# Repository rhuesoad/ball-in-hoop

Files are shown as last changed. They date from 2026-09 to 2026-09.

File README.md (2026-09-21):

# Ball in a Double Hoop

Code, CAD and documents of the master's thesis *Flying Ball in a Hoop — Design
of New Didactic Devices for Teaching of Control Engineering* (Rafaël Hueso
Adelantado), electromechanical engineering (mechatronics), ULB, 2025–2026.

Supervisors: Prof. Michel Kinnaert and Laurent Catoire.

A ball rolls inside two concentric hoops, turned by a single motor. The inner
hoop has a 90° gap. Four control tasks of increasing difficulty are posed on it:

| Task | Goal | Simulation | Bench |
|---|---|---|---|
| T1 | Bring the ball back to the bottom and hold it there | works | works, both hoops |
| T2 | Tracking | works | works, both hoops |
| T3 | Loop the loop | works | the ball leaves the track near the top (95–104°) |
| T4 | Throw the ball through the gap and catch it inside | works | not ported yet |

The thesis (`docs/thesis.pdf`) gives the model, the controllers and the results.

## Layout

The project works with a simulation, made on **Matlab**, and real hardware built with 
3D printing, and controlled with a Raspberry Pi controller and **Python**. 

| Folder | Content |
|---|---|
| `matlab/` | Model, controllers, trajectory planning, scenarios, and one example run per scenario |
| `python/` | Code that runs on the Raspberry Pi and drives the bench |
| `cad/` | OpenSCAD source of every printed part, one file per part |
| `analysis/` | Notebook that produces the report figures from the bench captures |
| `docs/` | Thesis and defence |

Each folder has its own README.

## Hardware

ODrive S1 driver, D5065 motor, AMT102-V encoder, Raspberry Pi with a Pi Camera,
and the printed parts in `cad/`.

## Where to pick it up

- **T4 on the bench.** The simulation works because the hoop is steered during
  the flight so that the gap faces the ball when it crosses the inner hoop
  (`matlab/scenarios/closed_loop/T4/T4_flying_ball.m`). The bench code in
  `python/tasks/t4_*.py` predates this and still loads the old plan.
- **T3 on the bench.** The two kept trials show where the ball leaves the track.
- **The model tests the ball centre only** when deciding whether it passes the
  gap, not the whole ball, so a clean mode sequence in simulation does not
  guarantee the ball clears the edge.
- **Hardware **: There is a play on the connection piece. Try to start from there
   to try to get better results on the looping itself.
- **More generally**, starting by the conclusion of the defence could help knowing 
  where to start to make things better in this project.

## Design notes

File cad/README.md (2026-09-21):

# CAD — printed parts

OpenSCAD source of every printed part (tested on OpenSCAD 2021.01). Open a part
file, render (F6), export to STL.

| File | Part |
|---|---|
| `outer_hoop_down.scad`, `outer_hoop_up.scad` | Outer hoop, two halves |
| `inner_hoop_down.scad`, `inner_hoop_up.scad` | Inner hoop, two halves |
| `motor_support.scad` | Motor support with its floor brackets |
| `motor_link.scad` | Link between the motor shaft and the hoops |
| `odrive_plate.scad` | Plate holding the ODrive S1 |
| `camera_rail.scad` | Camera rail, bolted to the M6 grid |
| `camera_carriage.scad` | Camera carriage, slides on the rail |
| `camera_clearance_test.scad` | Coupons to tune the rail clearance to a printer |
| `assembly.scad` | Whole bench, exploded view and 2D drawings (not a print file) |

The part files only select what to render. The geometry lives in `bench.scad`
(hoops and motor mount) and `camera_mount.scad` (camera rail).

`lib/nutsnbolts.scad` is "Norm Nuts and Bolts" by Johannes Kneer, under GPLv3.

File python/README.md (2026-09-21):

# Python — bench

Runs on the Raspberry Pi connected to the ODrive and the camera.

## Requirements

Python 3 with `numpy`, `scipy`, `opencv-python`, `odrive`, and `picamera2`
(Raspberry Pi only).

## Layout

| Folder | Content |
|---|---|
| `common/` | Ball detection, control loop and logging, estimators, hoop geometry |
| `experiments/` | Identification experiments E1 to E4 |
| `tasks/` | Control tasks T1 to T4: one config and one runner each, and the plans exported from MATLAB |
| `tools/` | Camera calibration and capture, ODrive calibration and tuning, one-off bench checks |

| Experiment | Measures |
|---|---|
| E1 | Motor and hoop inertia and friction |
| E2 | Ball friction, from free oscillations |
| E3 | The whole acquisition chain, from a hoop step |
| E4 | Static friction between ball and track |

## Running

From this folder, as modules:

```bash
python3 -m tasks.t1_run --psi-init 45
T1_HOOP=inner python3 -m tasks.t1_run --psi-init 45
python3 -m experiments.e2_run
python3 -m tools.odrive_calibration
```

Each run writes a `.npz` capture.

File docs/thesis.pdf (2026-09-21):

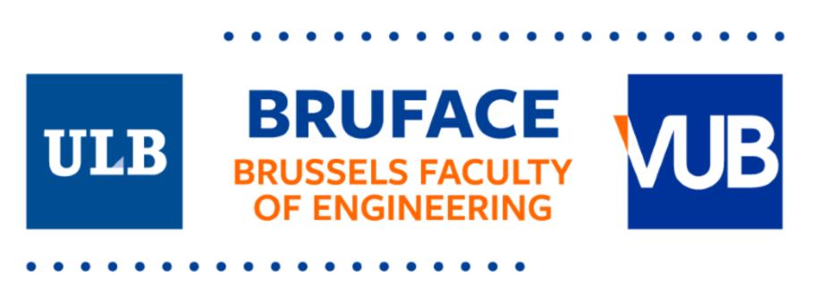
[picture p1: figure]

## [Date]

# Design of new didactic devices for teaching of control engineering

# Rafaël Hueso Adelantado

### Master thesis submitted under the supervision of

## Prof. Michel Kinnaert

### The co-supervision of

## Laurent Catoire

### In order to be awarded the Master’s Degree in

## Electromechanical Engineering – Robotics and Mechanical construction

### Academic year

2025-2026

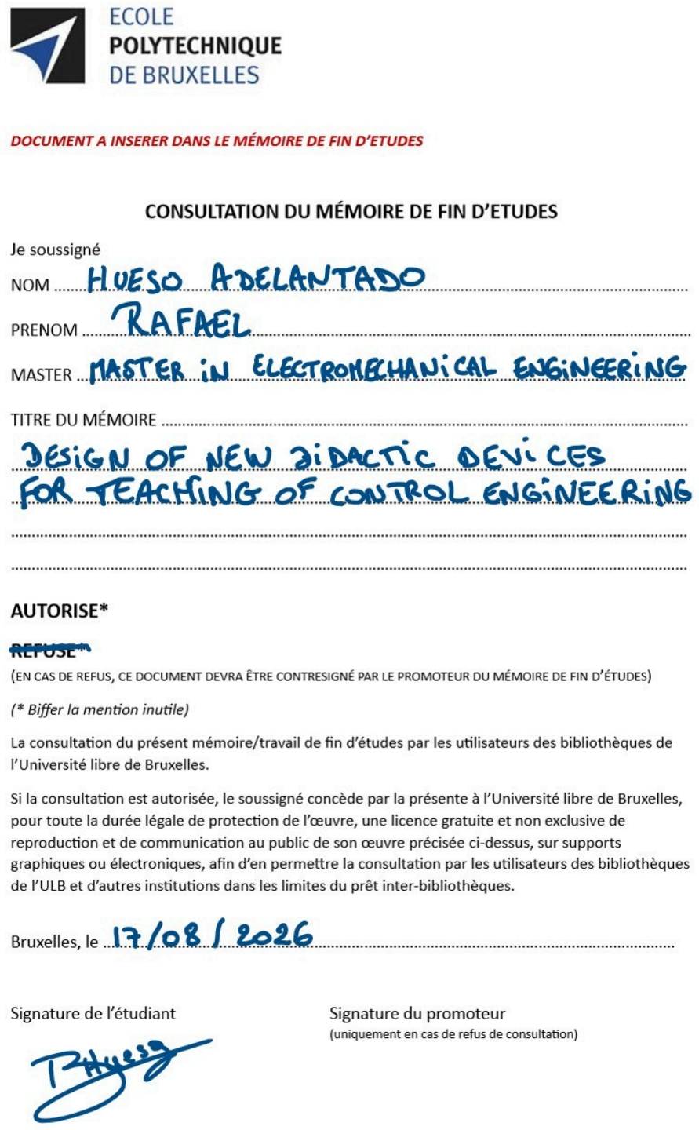
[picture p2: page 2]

Rafaël Hueso Adelantado
Master in Electromechanical Engineering - Robotics and Mechanical Construction Academic year 2025–2026
Design of new didactic devices for teaching of control engineering

Abstract

This thesis addresses the design, modelling, identification and control of a ball-and-hoop apparatus in double configuration, intended for the teaching of control engineering. The apparatus extends the single-hoop system introduced by Wellstead and takes as its starting point the double-hoop project of Gurtner and Zemánek, in which the ball may leave a rolling surface, travel through the air and land on another.
A hybrid model of the system is derived. It gives the ball access to four modes, three rolling modes and a free-flight mode, obtained from the Euler-Lagrange formalism, together with the guards and reset maps connecting them. The fourth mode follows from the opening cut in the inner hoop, which the published model does not cover. The resulting hybrid automaton is implemented and verified on a set of open-loop scenarios.
A prototype is then designed, built and characterised. Three experiments are performed on it to determine its parameters. The agreement between the model and the measured trajectories gives a mean root mean square error of 2.47° on the ball position.
Four control tasks of increasing difficulty are then formalised in a common optimal control framework. Stabilisation and reference tracking are achieved on the bench with a linear quadratic regulator, and the latency of the vision chain is shown to determine the loop rate below which the closed loop diverges, independently of the choice of gains. The looping manoeuvre is planned by direct collocation and stabilised by a time-varying regulator. It succeeds in simulation but fails systematically on the prototype, and the cause is traced to the reduced-order model, in which the no-slip constraint makes a violation of the law of Coulomb invisible to the optimiser. The flying ball task is consequently studied in simulation only.
The apparatus is functional as a teaching platform, and the modelling assumptions that limit its use for the harder tasks are identified explicitly.

Number of Words: 310
Keywords: ball-and-hoop, hybrid dynamical systems, optimal control, direct collocation, system identification, control engineering education.

i

## Acknowledgments

I would first like to express my gratitude to Professor Michel Kinnaert for his guidance throughout this thesis. His feedback and his expertise in the subject were crucial to this work. I also want to thank him for the freedom he left me in the direction it took.

I would also like to thank Laurent Catoire sincerely. His support was invaluable in the development of the prototype. I am grateful for the time he took to help me understand several technical aspects of the project, and for his patience whenever something had to be explained. His enthusiasm about the construction of the prototype made a real difference at a stage I was not confident about. I am also grateful to Fabio for making sure I had the widest possible access to the SAAS and to the printers that carried much of this work.

A special thanks goes to my music band. Without the PNTM, and now Sour, I would never have got through this year with the same determination.

Finally, I thank my family and friends for their support over the course of this year. Even when times were hard, I could always count on them. Special thanks to my mother, who convinced me never to give up, and to Paulina, Baptiste, Marion, Chloé, Anastasia, Gabor and all my friends and family, for making me feel supported and for giving me enormous confidence in my ability to finish this work.

ii

## Contents

Abstract | i
List of Figures | iv
List of Tables | vi
List of Abbreviations | vi
1 Introduction | 1
2 State Of The Art | 2
3 Mathematical Modelling | 10
4 System Design | 24
5 Parameter Identification | 32
6 Control Design | 43
7 Conclusion | 60

iii

Declaration of Generative AI and AI-assisted Technologies in the Writing Process | 61
Bibliography | 64
Appendices | 65
A Complete friction model for the ball | 65
B Field-Oriented Control | 67
C Inner Control Loop | 69
D Camera model and Image Acquisition | 71

## List of Figures

1.1 The prototype built in this work | | 1
2.1 First ball-and-hoop apparatus, motivated by the analogy with liquid sloshing | | 2
2.2 Flying Ball in Hoop prototype developed by the AA4CC group [2] | | 3
2.3 Common underactuated benchmarks. Each system has two degrees of freedom for a
single input. The actuated coordinate is shown in green, the free one in blue | | 3
2.4 Single-hoop configuration and its coordinates | | 5
2.5 Modes of the hybrid description of the ball-and-hoop system and the transitions between
them, following [2] | | 7
3.1 Diagram of the double-hoop system configuration | | 10
3.2 Hybrid automaton of the ball-in-double-hoop system. Each arrow is triggered when the corresponding guard vanishes. Losses of contact are governed by γ1, γ2 and γ3, impacts
by γ4, γ5 and γ6, and the passage over the opening of the inner hoop by γhole | 20
3.3 Open-loop trajectories of the six scenarios, released with τ = 0. The blue dot marks the initial position of the ball and the blue line its trajectory. Red dots mark the positions
at which a transition is triggered. The hoops are drawn at their starting orientation. . 22 4.1 Block diagram of the apparatus, showing the four subsystems and the signals exchanged
between them | | 25
4.2 CAD model of the two hoops, showing the tracks and the opening of the inner hoop. . | 27
4.3 Printed parts holding the apparatus | | 30
4.4 Electrical architecture of the prototype | | 31
5.1 Contact geometry of the idealised model and of the real prototype | | 32
5.2 Single frame from the vision chain, with the raw image, the separation through the
threshold and the detected ball centroid | | 33
5.3 Circles returned by the Hough transform on the same view | | 34
5.4 Steady-state torque against steady-state angular velocity, in both directions of rotation,
with the regression of each branch | 36
5.5 Free deceleration of the rotating assembly, with the regressions performed over the valid
portion of each run | 37
5.6 Free response of the ball released from several starting angles on the outer hoop, super-
posed over the trials | 38

iv

5.7 Extrema of a single trial and the two candidate envelopes fitted to them. The left panels
are in linear scale, the right ones in logarithmic scale, where a viscous decay appear as
a straight line | | 39
5.8 Measured hoop position over the trials of the campaign | | 40
5.9 Measured ball position over the trials, with the mean trajectory and the simulated one
superposed | 41
6.1 Measured ball position at two loop frequencies, with identical gains and from compa-
rable initial excursions | 48
6.2 Comparison between experimental LQR recovery trajectories and aligned simulations
from the same initial conditions | 49
6.3 Comparison between the tracking performance with the factory gains of the inner loop
(red) and the tuned gain (blue) values | 51
6.4 Measured ball position against its reference, with the hoop angle commanded by the
regulator shown on the right axis | | 51
6.5 Nominal trajectory of the looping manoeuvre | | 54
6.6 Simulation of the looping manoeuvre | | 55
6.7 Results of the looping manoeuvre on the bench, compared to the simulation results.
The simulation does the loop, while the bench fails | 56
6.8 Multi-phase trajectory of the flying ball manoeuvre, with the transitions marked in red. 59 B.1 Field-oriented current control loop as implemented on the ODrive S1. The outer loop control laws enter at the left of this loop, as a torque request converted to i

ref
q

through
the constant Kt
| 68
C.1 Step response of the inner velocity loop, with the factory gains, with the first-order response targeted by the design, and with the computed gains applied to the bench. . 70

v

## List of Tables

3.1 Physical parameters of the ball-and-hoop system | | 11
3.2 Parameters of the three rolling surfaces | | 13
4.1 Comparison of the ball candidates | | 25
5.1 Parameters identified in E1, averaged over the two directions of rotation | | 37
5.2 Physical parameters of the ball-and-hoop system | | 42
5.3 Physical parameters of the ball-and-hoop system, additions after component selection
and assembly | | 42
6.1 Equilibria of the ball-hoop system in each rolling mode | | 45
6.2 Retained weights for task T1 | | 47
6.3 Performance of the regulator against the specifications of task T1, for the outer hoop. | 49
A.1 Static friction coefficient required to maintain rolling contact, from (A.4) | | 65
C.1 Rise time, settling time and overshoot of the three step responses of Figure C.1 | | 70

## List of Abbreviations

BLDC | Brushless Direct Current
CPR | Counts Per Revolution
FOC | Field-Oriented Control
FOV | Field Of View
LQG | Linear Quadratic Gaussian
LQR | Linear Quadratic Regulator
NBR | Acrylonitrile Butadiene Rubber
OCP | Optimal Control Problem
PID | Proportional-Integral-Derivative
PLA | Polylactic Acid
PMSM | Permanent Magnet Synchronous Machine
PPR | Pulses Per Revolution
RMSE | Root Mean Square Error
TVLQR | Time-Varying Linear Quadratic Regulator

vi

## 1 Introduction

The objective of this master thesis is to design, control and implement a didactic device for the teaching of control engineering. The device selected in this document is a flying ball in a hoop. Students discover the dynamics of the system through lab sessions and learn to implement a control strategy bringing the ball onto the inner hoop of the prototype.

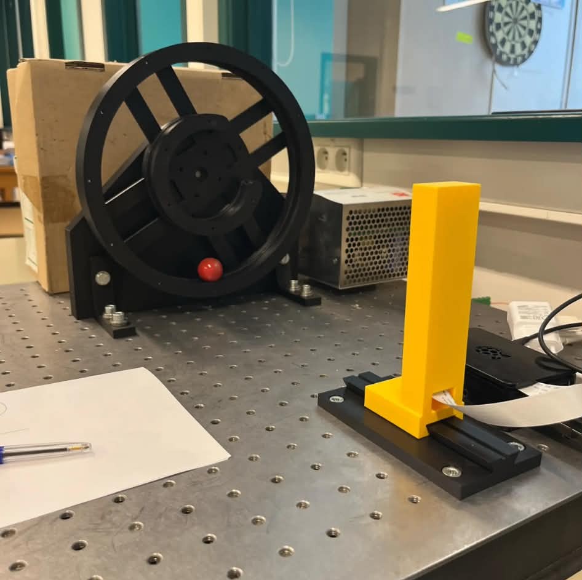
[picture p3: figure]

Figure 1.1: The prototype built in this work.

The ball and hoop is a well-known didactic device, with several commercial implementations available. It belongs to a family of classical benchmark systems used in control engineering education, alongside inverted pendulums and ball-and-beam apparatuses [1]. These systems share the important characteristic of being physically intuitive while still requiring careful attention when trying to model or control them.

In this system, the ball rolls inside a circular hoop, whose motion is controlled by a motor. The system studied in this thesis is further extended by a second hoop of smaller radius, mounted on the same axis. The dynamics become richer, since the ball can now leave a surface, travel through the air and land on the inner hoop. Such a system is no longer continuous, and is described as a hybrid system, alternating between continuous modes separated by discrete transitions [2]. The pedagogical value of the double-hoop configuration lies in its ability to demonstrate advanced control concepts, usually inaccessible during introductory courses, on a physically intuitive apparatus.

Four control tasks of increasing difficulty are formalised on this apparatus, from the stabilisation of the ball at an equilibrium to a manoeuvre in which it is launched, flies and is caught on the other hoop. Two of them are achieved on the prototype. The third fails on the bench while succeeding in simulation, and the analysis of that discrepancy is one of the results of this work.

This document begins with a state-of-the-art review, covering several ball-and-hoop prototypes and the strategies used to control them. The mathematical model of the complete system is then derived, including the equations of motion of each operating mode and the characterisation of the mode transitions. A chapter is dedicated to the choices made when designing the prototype, followed by the experimental identification of its parameters and the validation of the model against measurements. The control strategies are then implemented and their results reported, and a last chapter concludes with a summary of the achievements and perspectives for future work.

## 2 State Of The Art

This chapter reviews the literature on ball-and-hoop systems, from the original single-hoop configurations to the more recent double-hoop extensions. Its purpose is to identify the properties that make this platform a versatile teaching tool, and to highlight the elements that motivate the present work.

The chapter starts by presenting the historical context and motivation behind the ball-and-hoop system, before discussing its key dynamical properties. A review of existing implementations is then provided, first for single-hoop configurations and then for the double-hoop extension. A short conclusion summarises the current state of the literature and positions this thesis with respect to the existing work.

### 2.1 Historical Context and Motivation

The ball-and-hoop system was introduced in the control engineering literature by Wellstead in 1983, in the configuration shown in Figure 2.1(a) [3]. The motivation was to provide control laboratories with a mechanical apparatus serving an educational purpose, on which students could observe and control a nontrivial dynamic behaviour.

The apparatus was also developed as a physical analogue of liquid sloshing in partially filled containers. Sloshing refers to the oscillatory motion of a liquid in a tank subjected to external accelerations, and can be approximated by the motion of a pendulum, which is itself analogous to the motion of a ball rolling inside a rotating hoop [3], [4]. This analogy is shown in Figure 2.1(b). The phenomenon is critical in spacecraft propellant management, where fuel slosh can destabilise the vehicle and its control [5], and appears in every domain involving liquid transport, from fuel tankers to aircraft storage and industrial pumping. The system therefore carries an industrial reading alongside its pedagogical one, which is part of what has kept it in use.

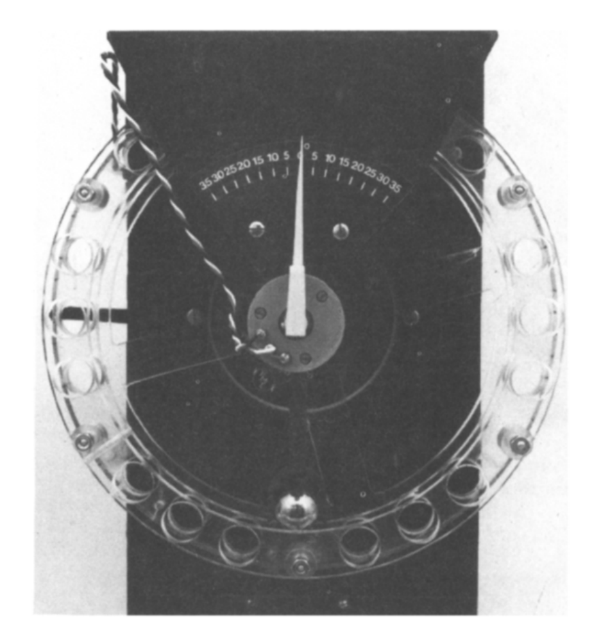
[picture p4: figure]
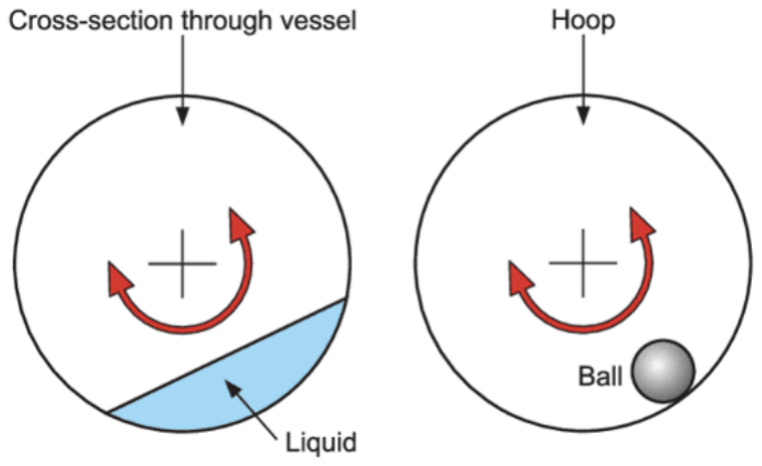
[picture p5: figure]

(a) First design of the ball-and-hoop apparatus [3]. | (b) Diagram showing liquid sloshing [3].

Figure 2.1: First ball-and-hoop apparatus, motivated by the analogy with liquid sloshing.

Following this publication, the system was commercialised and adopted in several university laboratories. Over the following decades, progressively more advanced control techniques were applied to the single-hoop configuration, from classical PID tuning [6] to Linear Quadratic Gaussian control [7], using both manual tuning and optimisation-based approaches [8], [9]. These studies confirm the versatility of this system as a control benchmark, covering a wide range of difficulty levels.

A significant extension was proposed later by Gurtner and Zemánek, who added a second hoop of smaller radius, mounted on the same axis [2]. The ball can then lose contact with a surface, travel through the air, and land on another. This transforms a purely continuous dynamical system into a hybrid one, and opens the apparatus to topics that the single-hoop configuration cannot reach, such as trajectory planning through mode transitions. The prototype is shown in Figure 2.2.

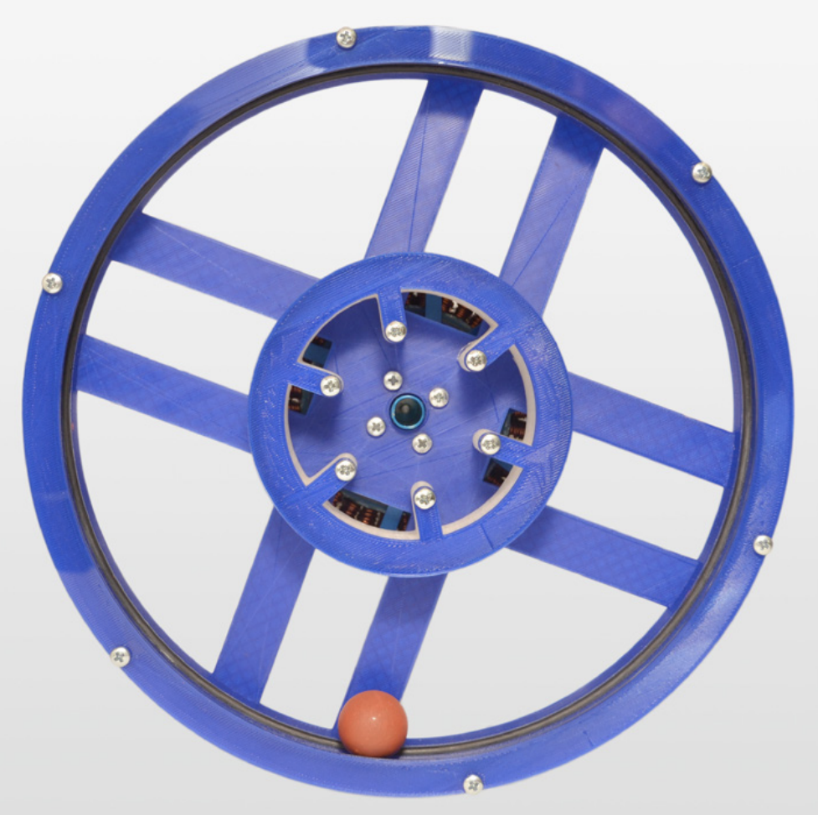
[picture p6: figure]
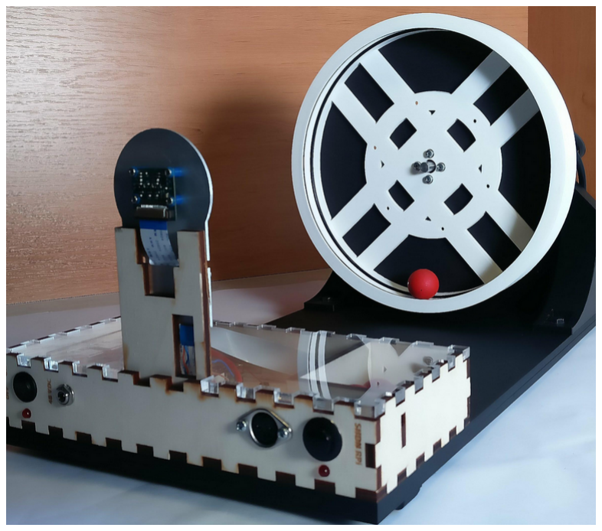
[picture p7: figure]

(a) Prototype. | (b) View from the ball-tracking camera.

Figure 2.2: Flying Ball in Hoop prototype developed by the AA4CC group [2].

Studies on double-hoop configurations nevertheless remain rare, and the extension is documented in essentially one peer-reviewed publication. That work establishes the feasibility of the apparatus and demonstrates two complex tasks on it, and the present thesis takes it as its starting point.

### 2.2 Key Properties

Two properties give the ball-and-hoop system its interest and its difficulty. The first is shared with a family of classical control benchmarks, and the second is what sets the double-hoop configuration apart from all of them.

### 2.2.1 Underactuation

The ball-and-hoop system belongs to the class of underactuated mechanical systems, defined as systems possessing fewer independent control inputs than degrees of freedom [10]. A single motor torque acts on the hoop, and the ball follows through the rolling contact alone. The two coordinates cannot be commanded independently, and the ball is never actuated directly.

Several classical benchmarks share this property. Figure 2.3 places the ball-and-hoop system among some of them [1]. The inverted pendulum, surveyed in over 140 references in a dedicated review [11], features an unstable upright equilibrium requiring active stabilisation. The reaction wheel pendulum
[12] uses a rotational actuator to influence the motion of the pendulum. The ball-and-beam system
[13] involves a ball rolling on a tilted beam, with simpler one-dimensional dynamics.
Cart and pendulum | Reaction wheel pendulum | Ball-and-beam | Ball-and-hoop, double

Figure 2.3: Common underactuated benchmarks. Each system has two degrees of freedom for a single input. The actuated coordinate is shown in green, the free one in blue.

All of them share the same count of two degrees of freedom for one input. They are distinguished by what happens at the contact between the actuated body and the unactuated one. The ball-and-hoop, in its double-hoop configuration, is the only one where the contact can be broken. The ball-and-hoop system also admits more equilibria than the others: each rolling surface admits its own, and the double-hoop configuration has three (see section 6). A controller can be designed for each of them separately, and more interestingly, the ball may be brought from one equilibrium to another.

Underactuation also has a frequency-domain reading. In the ball-and-hoop system, the transfer function from motor torque to ball position has a relative degree of four, since two integrations relate the torque to the hoop angle and two more relate the hoop motion to the ball position [3]. The two pendulums of Figure 2.3 reach only two, the actuator acting on the same body whose motion is to be controlled, while the ball-and-beam reaches four for the same reason as the ball-and-hoop, the actuator tilting a beam that in turn drives the ball. This count assumes the torque to be the input. Commanding the angular acceleration of the hoop directly, as done in section 6, removes the two integrations of the actuated body and brings the relative degree down to two.

A system of high relative degree responds to any input change with a phase lag that can be large, leaving little margin available for a feedback loop. Any additional lag, from a sensor, a filter or a computation for example, quickly consumes the phase that remains.

### 2.2.2 Hybrid Dynamics

A hybrid dynamical system evolves continuously within a given operating regime and undergoes abrupt transitions when certain conditions are met. The formal framework is built around three elements [14], [15]:
- a finite set of discrete modes, each with its own continuous dynamics,
- a set of guard conditions defining when a transition occurs,
- a set of reset maps specifying how the state is transformed at the transition instant.
The complete state is the pair formed by the continuous state and the active mode.

Such systems appear in many engineering applications, from walking robots alternating between support phases to gear shifting and power converters. In the double-hoop apparatus, the framework captures the physical behaviour directly. The ball alternates between rolling phases, where it is constrained to a hoop surface, and free-flight phases, where it moves under gravity alone, and each transition corresponds to a physically meaningful event, either a loss of contact or an impact.

The single-hoop configuration exhibits none of this. The ball remains on its track throughout, and the system is continuous. Adding a second hoop is what introduces the discrete transitions, which makes this apparatus one of the few educational benchmarks exhibiting hybrid behaviour naturally rather than by construction. The formalism itself is presented during the mathematical modelling of the system (see section 3).

### 2.3 Single-Hoop Systems

### 2.3.1 Physical Description

The single-hoop configuration consists of one circular hoop of radius Rh mounted on a horizontal axis and driven by an electric motor. A solid ball of radius Rb and mass mb rolls along the inner surface of the hoop under the combined effect of gravity and of the rotation of the hoop [3]. The state is described by the hoop angle θ, the ball angular position ψ measured from the downward vertical, and their derivatives, with the motor torque τ as input, as shown in Figure 2.4.

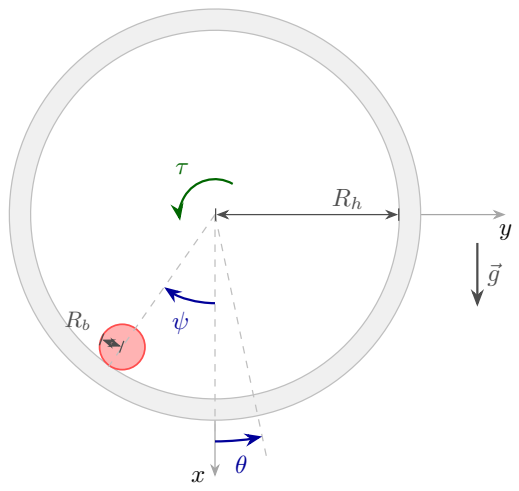
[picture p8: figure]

Figure 2.4: Single-hoop configuration and its coordinates.

The equations of motion are obtained by the Euler-Lagrange formalism, under the assumptions of pure rolling contact, rigid bodies and viscous friction at the contact and at the motor bearing. These equations are fully derived for the double-hoop configuration in the next section of this work (see section 3), of which the present configuration is a particular case. Two important features are commonly mentioned in the literature.

The first is the coupling between the ball and the hoop. Both ψ and θ appear in the equations. The hoop and the ball exchange angular momentum through the rolling contact, and neither can be moved without affecting the other. The second is the pendulum-like nature of the motion of the ball: the gravitational term is proportional to sin ψ, so that for small angles the ball behaves as a damped harmonic oscillator, but departs from that behaviour as soon as the excursion grows.

Some authors simplify the model by assuming the motor to be powerful enough and fast enough for the hoop angle to be treated as the direct input. This simplification discards the motor equation and leaves a second-order relation between θ and ψ [3]. It removes the relative degree of four discussed in subsection 2.2, and with it the difficulty that motivates most of the control work reported below. The present work keeps the cascade structure and the separation of time scales it relies on, but treats the commanded quantity as the hoop angular acceleration rather than the hoop angle, which preserves the dynamics of the hoop while acknowledging that the driver realises the command faster than the mechanical system responds. This choice is justified in section 4 and verified on the hardware in section 6.

### 2.3.2 Applications

The Ball and Hoop Apparatus CE109, developed by TecQuipment, is the commercial implementation of the system [16]. A steel ball rolls in a hoop of approximately 200 mm diameter driven by a DC servomotor, connected to a dedicated digital controller and to proprietary software for real-time implementation. Its purpose is pedagogical, and it supports a progressive sequence of experiments, from system identification through step and frequency responses to pole-zero analysis, PID design and cascade control with an inner velocity loop.

Several research groups have built custom prototypes to go beyond that sequence. Working outside a proprietary environment gives access to the low-level hardware, which is what allows optimal state feedback and automated tuning to be implemented and compared on the same plant [6], [7], [17]. These prototypes differ in their instrumentation, and in particular in how the ball position is measured, but they share the same dynamical structure and the same set of demonstrated tasks, namely stabilisation of the ball at the bottom of the hoop and tracking of a reference within a small neighbourhood of it.

### 2.3.3 Control Strategies

The single-hoop system has served as a basis for a broad range of control methods. Proportionalintegral-derivative (PID) control is the first method used on this system [3]. Classical tuning rules give a workable starting point on this plant, but can produce underdamped responses, a direct consequence of the high relative degree of the system (see subsection 2.2). Better results are reported on research prototypes where manual tuning is replaced by optimisation algorithms, which search the best sets of gains automatically by simulating the closed loop and keeping the values that minimise a performance criterion [6], [8], [9], [18].

Cascade control addresses the same difficulty by splitting the loop into a fast inner loop on the hoop velocity and a slow outer loop on the ball position. This separation exploits the natural hierarchy of time scales of the system, and it is the architecture of the commercial apparatus [16].

State-space methods represent the system by its state variables rather than by an input-output relation. This allows a feedback action on all of them from the single available input. The linear quadratic regulator computes this feedback by minimising a cost combining a quadratic penalty on the state deviation and a quadratic penalty on the control effort. The relative weight of the two is the design freedom. The gains follow from the solution of a single algebraic equation rather than from an iterative adjustment, making the design reproducible, and the resulting closed loop carries stability margins that are guaranteed by construction, rather than obtained by trial [19]. All states must however be available, which is easily done for the ball and hoop positions, but not necessarily for their velocities. The linear quadratic Gaussian design removes this limitation by combining the regulator with a Kalman filter, which estimates velocities from position sensors [7].

### 2.4 Double-Hoop Systems

### 2.4.1 Physical Description

The double-hoop configuration adds a second hoop of smaller radius, mounted concentrically inside the first and rotating with it. The ball can still roll on the inner surface of the outer hoop, but it may now leave that surface, travel through the air, and land on the outer surface of the inner one. Holding the ball on top of the inner hoop amounts to balancing a disk on a disk [20].

Three modes therefore describe the motion [2]. The ball rolls on the outer hoop, the ball is in free fall with no surface acting on it, or the ball rolls on the inner hoop. Figure 2.5 shows how the system passes from one to another.

Rolling,
outer hoop
S1

Free fall
S2

Rolling,
inner hoop
S3

γ1

γ2

γ3

γ4

Figure 2.5: Modes of the hybrid description of the ball-and-hoop system and the transitions between them, following [2].

Each arrow is triggered by a guard condition, denoted γ, which is a scalar function of the state changing sign at the instant of the transition. Two of them are losses of contact, and two are impacts:

- γ1 and γ4 mark the moment when the hoop stops pushing on the ball, on the outer and on the inner surface respectively. The ball is held against the track only as long as the normal force acting on it counteracts gravity, and it leaves as soon as that is no longer the case.
- γ2 and γ3 mark the moment when a ball in free fall meets a surface again, the outer hoop in the first case and the inner one in the second.

Crossing a guard changes the mode. A loss of contact leaves the position and the angular velocity of the ball continuous, since no impulsive force acts at that instant, and only the radial variables are reinitialised. An impact does not, since the ball lands with a velocity that the surface cannot accommodate, and the state after the shock is prescribed by a reset map built from the spin the ball carried through its flight.

The prototype distributed with the reference project carries an opening in the inner hoop, visible on the drawings of the repository and in the demonstration videos [21], [22]. The opening gives the ball access to the other surface of this hoop. The published model does not cover this configuration.

One assumption underlies every rolling mode, namely that the ball rolls without slipping on the surface it touches. It relates the spin of the ball to the two other angular velocities and reduces the number of degrees of freedom accordingly. It holds only as long as the surface can supply the tangential force the motion demands. High-friction rails are used in reported prototypes [2], [23]. The ball is treated throughout the literature as touching a single point of a cylindrical surface. The geometry obtained once the rails are built departs from that idealisation, and the correction is introduced in section 5.

### 2.4.2 Applications

The reference implementation is the Flying Ball in Hoop project, developed by the Advanced Algorithms for Control and Communication group at the Czech Technical University in Prague, and shown in Figure 2.2 [2]. It is the only peer-reviewed publication documenting a fully functional double-hoop system, and the drawings and codes are available in a public repository [21].

The hoops are 3D-printed, with rubber O-rings embedded in them serving as rails for a metal ball, and the assembly is driven by a brushless motor through a speed controller. The hoop angle needs no sensor, since it follows from integrating the input, and the ball position is measured by a camera whose images are processed on the same single-board computer that runs the control loop, both at 50 Hz. The angular velocity of the ball is estimated by an extended Kalman filter rather than measured, and the latency of the vision chain, of the order of two control periods, is compensated by predicting the state forward over that horizon. The dimensions of the prototype serve as a starting point for the present design and are reported in section 4.

The camera is the one instrumentation choice that the double-hoop configuration forces. Contact-based sensors, such as the infrared arrays or the coupled encoders used on single-hoop prototypes, report nothing while the ball is airborne, which is precisely the phase the second hoop exists to produce. An observer reconstructing the ball position from the hoop dynamics fails for the same reason, since the rolling constraint that couples the two no longer holds. A contactless sensor observing the ball through both regimes is therefore the only viable option, at the cost of the acquisition and processing latency a camera introduces [17].

Two tasks are proposed on this prototype [22]:

- the loop-the-loop, in which the ball starts at rest at the bottom of the outer hoop, completes a full revolution while keeping contact, and returns to rest. It must move fast enough over the top for the track to keep pushing on it.
- the flying ball, in which the ball leaves the outer hoop, falls, and is caught and held on the inner one. The state at the moment of departure must be chosen so that the flight and the impact that follow leave the ball in a condition the regulator of the inner hoop can absorb.

Both tasks go beyond the stabilisation and small-signal tracking reported on single-hoop systems. The model published alongside them is stated at the level of detail they require. The dynamics of the hoop are not modelled, since its angular acceleration is assumed to be commanded directly. The ball is assumed to roll without slipping, and to keep a constant spin during free flight.

Neither task uses the opening in the article, since the ball is caught on the convex face of the inner hoop during the flying ball scenario developed in it. The present work performs the same two tasks on an apparatus that carries the opening, which brings in a fourth mode and the transitions that go with it (see section 3).

### 2.4.3 Control Strategies

The tasks performed on the double-hoop configuration are not reachable with the methods used on single-hoop configurations. All of them stabilise the system near an equilibrium, but a loop-the-loop requires the ball to travel far from any equilibrium, and a flying ball passes through a phase in which the ball cannot be acted upon at all. The strategy developed to solve these tasks separates the problem into two, computing a nominal trajectory offline and stabilising it online [2].

The trajectory is obtained by numerical optimal control. Rather than choosing a reference by hand and hoping it can be followed, this method searches for the input history that minimises a chosen cost while satisfying the dynamics of the system and its physical limits. The search is made by direct collocation, which replaces the continuous problem by a finite one where the trajectory is described by its values at several instants. The dynamics become algebraic conditions between neighbouring instants [24]. The obtained trajectory is nominal, and any mismatch can accumulate. A feedback layer is therefore added, obtained by linearising the system along that trajectory rather than at a fixed point. This two-step approach is what makes both tasks feasible.

### 2.5 Conclusion

The literature on ball-and-hoop systems is strongly asymmetric. Four decades of work cover the single-hoop configuration, from the original apparatus of Wellstead to commercial implementations and research prototypes, with control methods ranging from classical tuning to optimal state feedback. All of it addresses the same regime, in which the ball stays near the bottom of its track and the system remains continuous.

The double-hoop extension is documented in a single peer-reviewed publication. That work models the apparatus as a hybrid system, poses two tasks that no linear method can solve, and demonstrates one of them on hardware. It establishes that the extension is feasible and that it is worth the additional complexity, and it is the starting point of the present thesis rather than a gap to be filled.

Three elements are nevertheless left open by the existing work, and they define the scope of the chapters that follow:

- The published model describes three modes and stops there. The prototype distributed with the project carries an opening in the inner hoop, which gives the ball access to a fourth rolling configuration that the model does not cover.
- The second task, in which the ball leaves one hoop and is caught on the other, is validated in simulation only. Its behaviour on hardware remains unknown.
- No assembly procedure or acceptance criterion is reported, so that reproducing the apparatus requires the reader to rediscover the choices that make it work.

This thesis addresses these three points. section 3 derives the four modes explicitly, together with the guards and reset maps connecting them. section 4 and subsection 4.4 describe the design and the assembly of a prototype, with the identification campaign needed to give the model its parameters. section 6 formalises four tasks of increasing difficulty on that prototype, from stabilisation to the flying ball, and reports what each of them achieves in simulation and on the bench.

## 3 Mathematical Modelling

The previous chapter described the ball-and-hoop apparatus and the behaviour reported on it. This chapter derives the equations governing that behaviour, for every configuration the double-hoop system admits. The derivation follows the Lagrangian framework and takes as its starting point the model of Gurtner and Zemánek [2], which covers three modes. The apparatus of this work carries an opening in the inner hoop, which gives the ball access to a fourth configuration, so the model is extended accordingly.

The chapter is organised as follows. This first section sets the frame, the parameters and the general form in which every equation of motion is written. The rolling modes are then derived, followed by the free-flight mode, where the contact disappears altogether. The transitions connecting these four modes are treated next, and the hybrid system is assembled from them. The model is finally implemented numerically, validated against a set of open-loop scenarios, and its limitations are stated.

### 3.1 Modelling Framework

### 3.1.1 Frame and Coordinates

The system is analysed in a fixed inertial frame (O, x, y), with the origin at the centre of rotation of the hoops. The x-axis points downward, in the direction of gravity, and the y-axis points horizontally to the right. The position of the ball is described in polar coordinates (r, ψ), and the rotation of the hoops by the angle θ. All angles are measured from the downward vertical and are positive in the counter-clockwise direction. These conventions are shown in Figure 3.1.

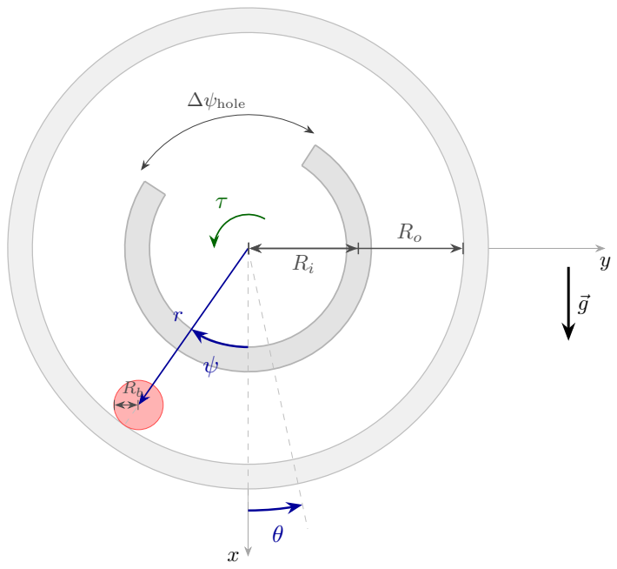
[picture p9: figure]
∆ψhole

Figure 3.1: Diagram of the double-hoop system configuration.

The continuous state of the system gathers these coordinates and their derivatives,

x = [ r, r, θ, ˙

˙θ, ψ, ψ˙
]
⊤. | (3.1)

The radial distance r locates the centre of mass of the ball with respect to the rotation axis, and ψ its angular position in the fixed frame. During the rolling modes, the ball is held against a surface, r is constant and the system reduces to two degrees of freedom. During free flight, all three coordinates evolve freely.

A fourth variable is needed to describe the motion completely. The ball turns about its own centre, and that rotation, called the spin and denoted φ, carries part of the kinetic energy of the system. In the rolling modes the spin is not independent, since the contact relates it to θ and ψ. In free flight the relation no longer holds and the spin evolves on its own. Both cases are treated with the modes they belong to.

### 3.1.2 Parameters

The physical parameters appearing in the model are shown in Figure 3.1 and collected in Table 3.1, with their units. Their proper values follow from the components selection (see section 4) and are identified on the prototype itself (see section 5).

Symbol | Description | Unit
g | Gravitational acceleration | m/s²
Rb | Ball radius | m
mb | Ball mass | kg
Ib | Ball moment of inertia | kg·m²
bb | Ball rolling friction coefficient | N·m·s/rad
Ro | Outer hoop inner radius | m
Ri | Inner hoop mid-radius | m
ti | Inner hoop wall thickness | m
∆ψhole | Angular width of the opening | rad
ψhole | Angular position of the opening centre | rad
Ih | Total moment of inertia of the rotating assembly | kg·m²
bm | Motor viscous friction coefficient | N·m·s/rad

Table 3.1: Physical parameters of the ball-and-hoop system.

The ball can roll on three surfaces. The inner surface of the outer hoop is concave, of radius Ro. The inner hoop, of mid-radius Ri and wall thickness ti

, presents a concave surface of radius Ri,in = Ri−ti/2 and a convex one of radius Ri,out = Ri + ti/2. The opening cut in its wall, of angular width ∆ψhole and centred at ψhole in the hoop frame, is what gives the ball access to the concave surface. On each surface, the centre of the ball travels along a circle whose radius depends on the curvature. The ball sits inside a concave surface and outside a convex one, so that

Reff =

Ro − Rb | on the outer hoop,
Ri,in − Rb | on the inner hoop, concave surface,
Ri,out + Rb | on the inner hoop, convex surface.

(3.2)

This effective radius is the distance from the rotation axis to the centre of the ball whenever contact is maintained, and it replaces r in the rolling modes.

The ball is treated here as touching the surface at a single point. The tracks fitted to the prototype hold it on two rings instead, which displaces the centre of the ball and the radius at which it rolls. This correction is derived once the tracks are designed (see section 5).

### 3.1.3 Lagrangian Formulation

The equations of motion of each mode are derived using Lagrangian mechanics. The Lagrangian is defined as L = T − V , where T is the kinetic energy of the system and V its potential energy. The generalised coordinates used in this formulation are q = [ r, θ, ψ ]

⊤, and for each of them the

Euler-Lagrange equations read
d
dt

∂L
∂q˙i
−

∂L
∂qi

= Qi

, | (3.3)

where Qi gathers the generalised forces associated with the coordinate qi

Friction is introduced through the Rayleigh dissipation function D, a quadratic function of the velocities whose derivative gives the dissipative force on each coordinate. The equations then become

d
dt

∂L
∂q˙i
−

∂L
∂qi

+

∂D
∂q˙i

= Q

ext
i
, | (3.4)

where Qext
i

contains only the external non-dissipative forces, here the action of the motor. Writing the dissipation this way is one of two equivalent routes, the other being to express the friction forces directly as generalised forces Qi

in (3.3). Both give the same equations, and the dissipation function is retained here because it gathers every friction term in a single scalar [25].

Two assumptions are made at this stage and hold throughout the chapter. The ball and the hoops are treated as rigid bodies, which is justified by the stiffness of the materials with respect to the loads encountered in normal operation. The motion is also assumed to remain in the vertical plane containing the rotation axis. Out-of-plane motion is prevented by the mechanical design, the hoops rotating about a fixed horizontal axis and the ball being laterally constrained by the width of the tracks. The measures taken during assembly to enforce this second assumption are described in section 5.

For every mode, the resulting equations are written in the matrix form

M(q) ¨q + C(q, q˙) ˙q + G(q) = B u | (3.5)

where M is the mass-inertia matrix, C gathers the Coriolis, centrifugal and damping terms, G is the gravity vector, B is the input distribution vector and u is the input.

### 3.1.4 Input of the System

The quantity commanded in this work is the angular acceleration of the hoops, u = ¨θ. However, the

motor delivers a torque. The driver uses its own control loop around the current (and therefore around the torque), at a rate much faster than the mechanical system responds. Seen from the outer loop, the commanded quantity is reached instantaneously, and the acceleration can be prescribed directly.

This cascade structure is the one adopted in the reference work [2]. The torque corresponding to a commanded acceleration follows from the equation of motion of the hoop, and is recovered whenever the actuator limits are checked.

With the frame, the parameters and the general form fixed, the equations of motion can be derived. The three rolling modes share enough structure to be treated together, and come first. Free flight, where the contact disappears and the two bodies separate, follows.

### 3.2 Rolling Modes

The three rolling surfaces that have been described lead to three different modes. They share the same global structure, since the ball is held on a circular surface turning about the same axis in each of them, but differ through the radius of the surface and the sign of its curvature. The derivation is therefore carried out once, in full, for the outer hoop, and the two remaining modes follow by substitution.

One assumption governs this derivation: the ball is assumed to roll on the contact point without slipping. Given the ratio between the radius of the ball and the ones of the surfaces, this assumption is reasonable.

### 3.2.1 Rolling Constraint

Rolling without slipping means that the two bodies in contact have the same velocity at the contact point. The point of the ball touching the surface is then momentarily at rest with respect to it, a condition that directly relates the spin of the ball with the two other angular velocities. When the ball rolls, for instance, on the inner surface of the outer hoop, the contact point moves with the tangential velocity at the contact radius, vhoop = Ro

˙θ.

The same point, seen from the ball, moves for two reasons: the centre of the ball travels along a circle of radius Reff, and the ball turns about this centre. The tangential velocity of the contact point on the ball is therefore vball = Reff ψ˙ + Rb φ˙. Respecting the no-slip condition means that

Ro

˙θ = Reff ψ˙ + Rb φ,˙ | hence | φ˙ =

Ro
Rb

˙θ −

Reff
Rb
ψ.˙ | (3.6)

The spin of the ball is thus determined by ˙θ and ψ˙
, and the system retains two degrees of freedom in this mode. The same reasoning applies to the concave surface of the inner hoop, with Ri,in replacing Ro. On the convex surface, the geometry differs, and the contact point on the ball moves in the opposite direction relative to its centre. The condition becomes
φ˙ = − | Ri,out Rb ˙θ + | Reff
Rb
ψ.˙ | (3.7)

The three cases are gathered by introducing the radius R of the surface on which the ball rolls, and a sign σ carrying its curvature,

φ˙ = σ

R
Rb

˙θ −

Reff
Rb

ψ˙

, σ =

+1 on a concave surface,

−1 on a convex surface,

(3.8)

with the values of R, Reff and σ for each mode collected in Table 3.2.

Mode | R | Reff | σ
Rolling on the outer hoop | Ro | Ro − Rb | +1
Rolling on the inner hoop, concave surface | Ri,in | Ri,in − Rb | +1
Rolling on the inner hoop, convex surface | Ri,out | Ri,out + Rb | −1

Table 3.2: Parameters of the three rolling surfaces.

### 3.2.2 Derivation on the Outer Hoop

In this mode the ball is held against the inner surface of the outer hoop, so that r = Reff is constant and r˙ = ¨r = 0. The generalised coordinates reduce to θ and ψ.

Kinetic energy
The kinetic energy gathers the motion of the ball and that of the hoops. The centre of mass of the ball travels along a circle of radius Reff at the speed Reff|ψ˙
| and turns about its own centre, and the rolling constraint expresses this rotation in terms of the two generalised velocities (as seen in (3.8)). The hoops rotate about the fixed axis. The contribution of each of them gives

Tball = Tball,trans + Tball,rot =

1
2 mbR

2

eff ψ˙² +
1/2 Ib φ˙

2

Thoop =

1/2 Ih

˙θ
2
,

(3.9)

(3.10)

and the total kinetic energy is the sum of these contributions,

T =

1
2mbR

2

effψ˙² +
1/2 Ib

Ro
Rb

˙θ −

Reff
Rb

ψ˙

2
+

1/2 Ih

˙θ
2
. | (3.11)

Potential energy
The only contribution comes from the ball, since the hoops turn about their own centre of mass. Since the x-axis points downward, the height of the centre of the ball above the origin is −Reff cos ψ, and taking the reference at the rotation axis,
V = − mb g Reff cos ψ. | (3.12)

Dissipation
Energy is dissipated at the bearing of the motor and at the contact between the ball and the surface. Both of them are modelled as viscous, proportional to the corresponding velocity. This is an idealisation, as other dissipation sources may have an influence too: rolling resistance, static friction, aerodynamic drag [23]. Each of them is estimated for the present geometry in Appendix A, showing that drag is negligible, static friction stays within what the tracks can supply and that rolling resistance is not negligible but cannot be carried into a linear model.

The dissipation associated with the contact acts on the spin of the ball, leading to

D =
1/2 bm

˙θ
2 +
1/2 bbφ˙

2 =
1/2 bm

˙θ
2 +
1/2 bb

Ro
Rb

˙θ −

Reff
Rb

ψ˙

2
. | (3.13)

Equation of motion for the hoop
The Lagrangian is L = T − V . Differentiating with respect to ˙θ and collecting the terms gives

∂L
∂ ˙θ

= Ib

Ro
Rb

Ro
Rb

˙θ −

Reff
Rb

ψ˙

+ Ih

˙θ =
Ih + Ib

R²
o
R²
b

!
˙θ − Ib

RoReff
R²
b

ψ,˙

d
dt

∂L
∂ ˙θ

=

Ih + Ib

R²
o
R²
b

!
¨θ − Ib

RoReff
R²
b

ψ. ¨

(3.14)

(3.15)

The Lagrangian does not depend on θ itself, so ∂L/∂θ = 0. This reflects the rotational symmetry of the apparatus, the equilibria being independent of the absolute orientation of the hoops.

The dissipative contribution is

∂D
∂ ˙θ

= bm

˙θ + bb

R²
o
R²
b

˙θ − bb

RoReff
R²
b
ψ,˙ | (3.16)

and the equation of motion for the hoop follows,

Ih + Ib

R²
o
R²
b

!
¨θ − Ib

RoReff
R²
b

ψ¨ +
bm + bb

R²
o
R²
b

!
˙θ − bb

RoReff
R²
b
ψ˙ = τ | (3.17)

Equation of motion for the ball The same operations on ψ give

∂L
∂ψ˙

= −Ib

RoReff
R²
b

˙θ +
mbR

2
eff + Ib

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
= −Ib

RoReff
R²
b

¨θ +
mbR

2
eff + Ib

R²
eff
R²
b

!
ψ, ¨

∂L
∂ψ = − mb g Reff sin ψ,

(3.18)

(3.19)

(3.20)

the last expression being the gravitational term, which is the only nonlinearity of the model. The dissipative contribution is
∂D
∂ψ˙

= −bb

RoReff
R²
b

˙θ + bb

R²
eff
R²
b
ψ,˙ | (3.21)

and the equation of motion for the ball follows,

−Ib

RoReff
R²
b

¨θ +
mbR

2
eff + Ib

R²
eff
R²
b

!
ψ¨ − bb

RoReff
R²
b

˙θ + bb

R²
eff
R²
b
ψ˙ + mbgReff sin ψ = 0 | (3.22)

No input appears in this equation, which is the analytical expression of the underactuation discussed in the state of the art (see subsection 2.2). The motor acts on the hoop, and the ball responds only through the coupling terms.

### 3.2.3 General Form of the Rolling Modes

Writing q = [ r, θ, ψ ]

⊤ with r = Reff constant, the rolling modes take the form of (3.5) with

M =

mb | 0 | 0
0 | Ih + Ib

R²
R²
b

−Ib

| | R Reff R²

b
0 | −Ib
| R Reff R²

b

mbR²
| | eff + Ib

R²
eff
R²
b

, G =

0
0
mb g Reff sin ψ
,

C =

0 | 0 | 0

0 bm + bb

R²
R²
b

−bb

| | R Reff R²

b
0 −bb | R Reff R²

b

bb

| | R²
eff
| | R²
b

, | B =

0
1
0

(3.23)

In this matrix form, the radii values are written using the general notations R and Reff. This is because the derivation is the same on the two other rolling surfaces.

The structure of (3.23) shows where the difficulty of the system lies: The matrices M and C have non-zero off-diagonal terms, so that the two coordinates cannot be treated separately. The gravity vector acts on the ball alone, and depends on ψ through a nonlinearity. The input vector acts on the hoop alone, so that the ball is reached only through the coupling. These three observations influence the whole control design (see section 6).

### 3.3 Free-Flight Mode

When the ball leaves a surface, the contact disappears and with it the constraint that tied the radial coordinate to the geometry. The three generalised coordinates become free, and the motion of the ball separates completely from that of the hoops.

### 3.3.1 Equations of Motion

Energies and dissipation
The centre of the ball now moves with a radial and a tangential component, while the hoops keep turning under the action of the motor,

Tball =

1
2 mb
r˙

2 + r

2ψ˙²

,

Thoop =

1/2 Ih

˙θ
2

(3.24)

(3.25)

The potential energy retains the same form as before, with r in place of Reff, and the dissipation function reduces to the bearing of the motor, since no contact remains,

V = − mb g r cos ψ, D =
1/2 bm

˙θ
2
. | (3.26)

Aerodynamic drag on the ball is neglected here as well, its magnitude being small compared with gravity and inertia at the velocities and over the durations encountered on this apparatus (see Appendix A).

Hoops
The Lagrangian depends on θ only through its derivative, and the equation of motion for the hoops is that of a rotating body subject to viscous friction,

Ih

¨θ + bm

˙θ = τ | (3.27)

The ball does not appear in it, and the hoops do not appear in the equations of the ball either.

Ball
Applying the Euler-Lagrange equations to the radial and angular coordinates gives

d
dt

∂L
∂r˙

= mbr, ¨

∂L
∂r = mbrψ˙² + mbg cos ψ,

d
dt

∂L
∂ψ˙

= 2mbrr˙ψ˙ + mbr

2ψ, ¨

∂L
∂ψ = − mbgr sin ψ.

(3.28)

(3.29)

Dividing by mb and rearranging gives the equations of motion of the ball, which match the expressions reported in [2].

r¨ = rψ˙2 + g cos ψ

ψ¨ = −

1
r
g sin ψ + 2 ˙rψ˙
| (3.30)

These two equations describe a projectile under uniform gravity. In Cartesian coordinates, the trajectory is exactly parabolic, and (3.30) is the same equation written in the polar frame. The term rψ˙2 is
the centrifugal contribution to the radial equation, while 2 ˙rψ˙ the Coriolis contribution to the angular

one.

Matrix form

M =

mb | 0 | 0
0 | Ih | 0
0 | 0 | mbr

2

, | G =

−mbg cos ψ
0
mbgr sin ψ
,

C =

0 | 0 | −mbrψ˙
0 | bm | 0
2mbrψ˙ | 0 | 0

, B =

0
1
0

(3.31)

### 3.3.2 Spin During the Flight

The spin of the ball does not appear in (3.30), since no contact couples it to the other coordinates and no torque acts about the centre of the ball. It is however still relevant, since the ball carries it through the whole flight and lands with this spin on the next surface. The spin is assumed constant during free flight [2]. Denoting by φ˙

− the value taken just before a transition and by φ˙ + the value

just after it, as everywhere in this work, the spin the ball leaves with at liftoff is the one it arrives with at the next impact,

φ˙(t) = ˙φ

+
tlo

= ˙φ

−
timp
, | t ∈ [tlo, timp ], | (3.32)

where tlo and timp are the instants of liftoff and impact. The spin must be carried alongside the state during this mode, and it enters the state again after the impact.

### 3.4 Hybrid System Formulation

The four modes derived above describe the motion when the ball is in one of them. The passages from one to another require two other elements: a condition marking the instant of the transition, called a guard, and a rule that gives the state immediately after reaching this condition, called a reset map.

Six transitions exist in this model, and each of them carries its own guard γi

| | , following the notation
of the reference work [2]. Every guard is built so that it stays negative while the mode is active and vanishes at the instant of the transition, which is what allows a solver to locate the crossing by a change of sign. Each transition is stated below, with the physical situation it describes, the guard that detects it and the reset map that follows. The whole is then assembled into a formal hybrid system.

### 3.4.1 Losses of Contact

A surface holds the ball only by pushing on it, so the ball leaves as soon as that push would have to become a pull. Consider a ball rolling at the distance Reff from the axis, so that r is constant and r¨ = 0. Projecting the second law of Newton on the radial direction, the centripetal acceleration is produced by the radial component of gravity, g cos ψ directed outwards, and by the normal force N, directed inwards on a concave surface and outwards on a convex one,

N = σ mb

g cos ψ + Reff ψ˙ 2
| , | (3.33)

with σ taken from Table 3.2. Contact requires N ≥ 0, so the guard of every loss of contact is the negative of that force.

- Outer hoop to free flight. The surface is concave, and the ball leaves when

γ1 = −

g cos ψ + Reff ψ˙ 2
= 0, | Reff = Ro − Rb. | (3.34)

Near the bottom of the hoop, gravity and the centripetal requirement both press the ball against the track. Near the top, cos ψ becomes negative and the two compete, so the ball stays only if it moves fast enough.

- Inner hoop, concave surface, to free flight. The same expression applies, with the effective radius of that surface,

γ2 = −

g cos ψ + Reff ψ˙ 2
= 0, | Reff = Ri,in − Rb, | (3.35)

the smaller radius making the centripetal term grow faster for a given angular velocity. This surface carries a second guard, described below.

- Inner hoop, convex surface, to free flight. The surface is convex and pushes the ball outwards, which reverses the sign,
γ3 = g cos ψ + Reff ψ˙ 2 = 0, | Reff = Ri,out + Rb. | (3.36)

The situation is the reverse of the concave case: the ball is held at the top of the hoop, where gravity presses it against the wall, and leaves as soon as it acquires enough speed.

A fourth condition applies on the concave surface of the inner hoop alone. The wall is interrupted by the opening, and where the wall is absent there is no contact to lose. The ball then enters free flight whatever the value of (3.35), as soon as it reaches the angular span of the opening,

γhole =

1
2∆ψhole − |wrap(ψ − θ − ψhole)| = 0, | (3.37)

where wrap maps an angle onto [−π, π] and the difference ψ − θ is the angular position of the ball expressed in the frame of the hoops, in which the opening is fixed. This guard does not open a transition of its own. It decides which of the two surfaces of the inner hoop the ball can reach, since the concave one is accessible only through the opening, and it also removes the support from a ball already rolling on that surface.

No impulsive force acts at any of these transitions, so every state variable is continuous across them,

r

+ = Reff, | r˙
+ = 0, | θ⁺ = θ

−,
˙θ

+ = ˙θ

−, | ψ⁺ = ψ
−, | ψ˙ + = ψ˙ − | (3.38)

the radial velocity being zero because r was constant during rolling and the ball leaves tangentially. The spin also passes through unchanged, and its value at that instant, given by the rolling constraint
(3.8) evaluated on the last contact state, is the one carried through the flight according to (3.32).

### 3.4.2 Impacts

A ball in free flight reaches a surface when its radial distance meets the corresponding effective radius. Three surfaces are available, and the ball arrives on each of them from a different side.

- Free flight to the outer hoop. The ball travels outwards and meets the concave surface from the inside,
γ4 = r − (Ro − Rb) = 0. | (3.39)

This surface is continuous over its whole circumference, so no further condition applies.

- Free flight to the inner hoop, concave surface. The ball is inside the inner hoop and meets the wall from within,
γ5 = r − (Ri,in − Rb) = 0, | (3.40)

subject to γhole < 0 at that instant, since the wall is absent over the span of the opening and the ball then continues its flight.

- Free flight to the inner hoop, convex surface. The ball travels inwards and meets the wall from outside, which reverses the sign,
γ6 = (Ri,out + Rb) − r = 0, | (3.41)

subject to the same condition on the opening.

An impact differs from a loss of contact in that the velocity of the ball changes abruptly, and the equations of motion, which describe a flow, say nothing about an instantaneous event. The state after the shock follows from a reset map, which is a modelling choice.

The map used here treats the impact as perfectly inelastic in the normal direction and perfectly adherent in the tangential one. The radial velocity is annihilated, the ball being snapped to the surface, and the tangential motion is redistributed so that rolling is established immediately. The redistribution follows from the rotation the ball carries about its own centre. Writing that the spin after the impact must satisfy the rolling constraint (3.8), and that the ball arrives with the spin (3.32) it kept through the flight,

ψ˙ + = ψ˙ − +

˙θ

− − σ

Rb
R

φ˙

−

,

r

+ = Reff, | r˙
+ = 0, | θ⁺ = θ

−,
˙θ

+ = ˙θ

−, | ψ⁺ = ψ
| − | (3.42)

the added term measuring the mismatch between the rotation the ball carries and the rotation the contact requires, and the angular velocity of the hoops being unaffected, since the inertia of the hoop assembly is large compared with that of the ball.

### 3.4.3 Complete System

The four modes (3 in rolling, 1 in free-flight) and the transitions derived so far form a hybrid dynamical system, described by the quintuplet H = (Q, X , f, G, R) [14], [15]:

- the discrete modes Q = {q1, q2, q3, q4}, where q1 is rolling on the outer hoop, q2 is free flight, q3 is rolling on the concave surface of the inner hoop and q4 is rolling on its convex surface,
- the continuous state space X ⊂ R

6
, whose elements are the vectors (3.1), together with the spin carried during q2,
- the continuous dynamics f, given by (3.5) with the matrices (3.23) for the rolling modes and
(3.31) for free flight,
- the guard conditions G = {γ1, . . . , γ6, γhole}, given by (3.34) to (3.41) and (3.37),
- the reset maps R, given by (3.38) for a loss of contact and by (3.42) for an impact.

The complete state of the system is the pair formed by the continuous state and the active mode. Between two transitions the system follows the dynamics of that mode, and when a guard vanishes the corresponding reset map is applied, the mode changes, and the evolution continues under the new dynamics. The resulting structure is shown in Figure 3.2.

The six guards reduce to two expressions once the sign σ of Table 3.2 is used to carry the curvature of the surface. Every loss of contact is written as γ = −σ (g cos ψ + Reffψ˙ 2
), which is the normal force
(3.33) taken with the opposite sign, and every impact as γ = σ (r − Reff), the sign expressing that the ball reaches a concave surface from the inside and a convex one from the outside.

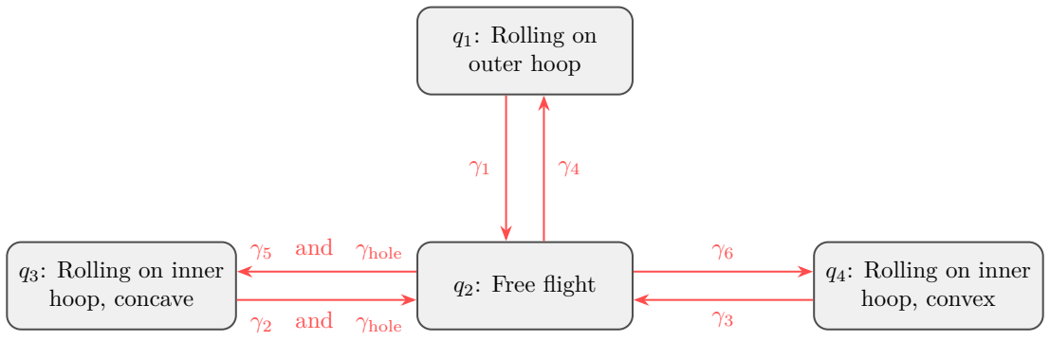
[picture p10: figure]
q1: Rolling on outer hoop; q2: Free flight q3: Rolling on inner hoop, concave; q4: Rolling on inner hoop, convex; and γhole

Figure 3.2: Hybrid automaton of the ball-in-double-hoop system. Each arrow is triggered when the corresponding guard vanishes. Losses of contact are governed by γ1, γ2 and γ3, impacts by γ4, γ5 and γ6, and the passage over the opening of the inner hoop by γhole.

Free flight is the only mode connected to all the others, which reflects the physical arrangement of the apparatus. The ball can reach a surface only by travelling through the air, and can leave one only in the same way, so that the three rolling modes are never adjacent and no transition connects them directly.

### 3.5 Numerical Implementation

The hybrid model derived above is implemented in MATLAB. This implementation is used throughout the rest of this work, to size the components, analyse the identified parameters, design the test controllers and compare them with the results obtained on the real plant. Its purpose is therefore not only to reproduce the equations, but to serve as a reference against which the prototype is compared.

Two requirements follow from this purpose: the same code must simulate the system in open loop and in closed loop, and each run must be saved, to remain comparable with a measurement. This section reports the choices made to satisfy these requirements, the open-loop results they produce, and the limitations of this model.

### 3.5.1 Implementation

The equations of motion of the active mode are integrated with the ode15s solver of MATLAB [26]. Two families of solvers exist for this task.

- An explicit method computes the next state directly from the current one, which is cheap per step but forces the step to shrink whenever a fast dynamic is present, whatever its amplitude, since a step too large for that dynamic makes the integration diverge.
- An implicit method instead solves an equation at each step to find a state consistent with the dynamics at the end of the interval, which costs more per step but remains stable with large steps.

The second family is the one suited to stiff problems, that is to problems containing dynamics evolving on very different time scales, where an explicit method would spend its effort resolving a fast transient that has long since died out. The rolling dynamics alone are not stiff. What makes the implicit solver the right choice is the closed-loop use the implementation is written for: the controllers add the loop of the driver, whose dynamics are an order of magnitude faster than the ball, and the transitions can bring abrupt changes of regime. The solver is therefore chosen once for the hardest case rather than switched by scenario, the cost on the passive runs being a fraction of a second either way. The solver returns a continuous representation of the solution, so a trajectory can be evaluated at any instant, and compared to a measured trajectory point by point.

Transitions are located by the event mechanism of the solver, with one function declared per guard. When an event is triggered, the integration stops and the reset map is applied to the last recorded state. The integration then resumes in the new mode.

The hole is taken into account by adding the hole condition in the event detection, so that no guard fires while the ball faces the opening. At the instant of a crossing, the state sits exactly on the guard. In practice, the integration resumes slightly past it, so that the same event is not detected infinitely. The spin of the ball is stored at every loss of contact, and recovered at the next impact.

Each run is finally stored with its trajectory, the mode intervals and the parameters that produced it, so that the different figures can be traced back.

### 3.5.2 Open-Loop Results

The implementation is used on a set of open-loop scenarios, each declaring an initial mode and state, with τ = 0. Two verifications are made on them: a behaviour verification to check that the expected modes, transitions and states are active, and an energetic one, that verifies if the total energy stays constant if no dissipating mechanism is left in the process (with bb = bm = 0 and no torque applied).

Six scenarios are reported in Figure 3.3. Two exercise a rolling mode on its own, and the four others cross at least one transition. All transitions and modes are used in the present scenarios.

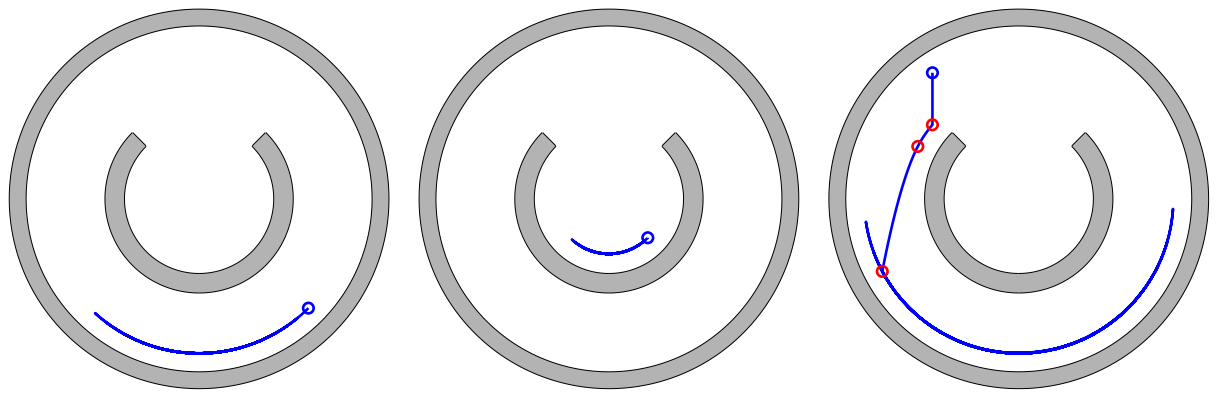
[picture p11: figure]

(a) Rolling on the outer hoop, released at rest away from the
(b) Rolling on the concave surface of the inner hoop, released at rest
(c) Free flight beside the opening, landing on the convex surface of

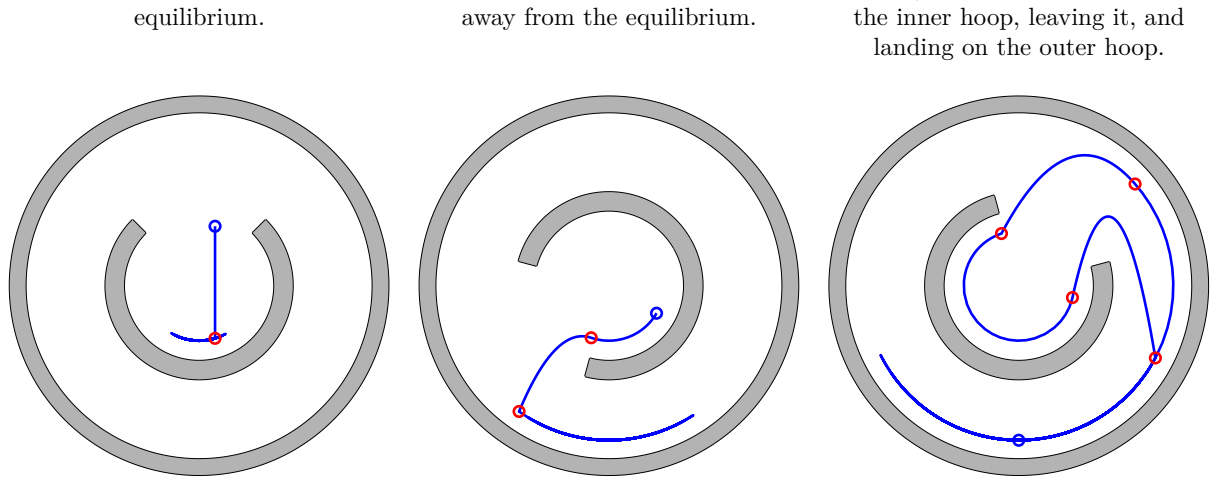
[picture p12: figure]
equilibrium.; away from the equilibrium.; the inner hoop, leaving it, and landing on the outer hoop.

(d) Free flight above the opening, passing through it and landing on the concave surface of the inner hoop.
(e) Rolling on the concave surface of the inner hoop, leaving it through the opening, and landing on the outer hoop.
(f) Ball launched from the outer hoop with an initial velocity, reaching the inner hoop, leaving it, and landing back on the outer hoop.

Figure 3.3: Open-loop trajectories of the six scenarios, released with τ = 0. The blue dot marks the initial position of the ball and the blue line its trajectory. Red dots mark the positions at which a transition is triggered. The hoops are drawn at their starting orientation.

Each mode is reached, and every transition is triggered where it should be. The six scenarios show every transition of the model at least once. The guard bounding the opening hole is seen twice: when it lets the ball in, and when it lets it out. The losses of contact preserve the state, and the landings are located within 6 × 10⁻¹⁴ m of the geometric contact radius, so that the reset map applies to a state

that already satisfies the guard, rather than correcting it.

The energetic tests meet the expectations: the relative deviation stays below 0.013 % over three seconds and below 0.026 % over ten. The energy changes by less than 1 × 10⁻⁷ J across a loss of contact,

and it always decreases across an impact.

This decrease at impacts is large, between 91 % and 99 % carried into the impact. This follows directly from the two assumptions of the reset map. The radial velocity, mostly corresponding to the velocity at the end of a fall, is entirely absorbed. What remains of the tangential motion is also reduced by the establishment of rolling, leading to this decrease. This means that the simulation is optimistic about captures, and cannot directly discriminate between a ball caught and a ball that would have bounced away. If the prototype shows a ball bouncing or sliding on landing, introducing a restitution coefficient is one of the first changes to make [27], [28].

Dissipation itself can also be a limiting factor of this simulation: it is carried by two viscous coefficients alone, while other mechanisms are considered negligible or not represented in a differentiable model (see Appendix A). Their effect can appear, and appear in the error to be compensated.

The ball is finally treated here as touching a cylindrical surface at a single point. In practice, some tracks hold the ball on two rings. The resulting geometry is properly derived once the rails are selected (see section 5).

Apart from these limitations, the model is now complete and its implementation validated. It is written in terms of quantities taken from a reference design rather than from an apparatus that exists [2]. The chapters that follow show the components selection and parameters identification that allow a proper comparison with the simulation.

## 4 System Design

The two previous chapters described what a ball-and-hoop apparatus is and derived the equations governing it. Neither of them concerns a physical object: the state of the art reports what others have built, and the model is written in terms of masses, radii and friction coefficients that no prototype has yet supplied. This chapter focuses on selecting components that give those symbols a proper value.

The selection follows two series of requirements. First, the apparatus must be able to perform the four tasks this work sets out to demonstrate, which bounds the torque, the resolution and the timing of the whole chain. Second, the apparatus must keep valid the assumptions on which the mathematical model rests, or ensure that corrections are applicable, since a component that violates one of them makes the model useless. This section derives the different requirements, before describing the components selection and assembly.

### 4.1 Requirements

Four tasks of increasing difficulty are set as objectives for the prototype. They are formalised as control problems in section 6, and each of them demands a performance that directly influences the selection of the components.

T1 Regulation. The ball is held at one of the equilibria of the system, against small perturbations. The demand is on measurement rather than on power, since a static equilibrium requires no sustained effort, and the resolution on the ball position sets the smallest deviation the controller can react to.

T2 Tracking. The ball follows a time-varying reference within the same rolling mode. The reference now moves, so the loop must be fast compared with the motion it is asked to reproduce, which sets the sampling frequency of the whole chain and bounds the acceptable latency of the sensors.

T3 Loop-the-loop. The ball completes a full revolution while keeping contact with the track. Contact at the top requires the ball to carry enough speed for the surface to keep pushing on it, and that speed must be built up against gravity, which sets the peak torque the actuator must deliver. The contact must also sustain the tangential force that rolling demands, which bears on the surface of the tracks rather than on the motor.

T4 Flying ball. The ball leaves one surface, travels through the air and is caught on another. During the flight the ball is mechanically disconnected from the hoops, so any sensor relying on that contact reports nothing at the moment the information matters most. This task alone rules out every contact-based measurement of the ball position.

A second set of requirements comes from the model itself. Several of the assumptions on which section 3 rests are properties of the hardware rather than of the mathematics. Each of them is therefore raised where the component that protects it is selected.

These demands are not independent. This is why the selection is made iteratively, each component being chosen against the requirements and against the components already selected.

### 4.2 Architecture

The apparatus is organised into four subsystems, shown in Figure 4.1. The controller evaluates the control law and issues a command, the actuation system converts it into a torque applied to the hoops, the mechanical assembly carries the ball, and the sensing system returns the measurements the

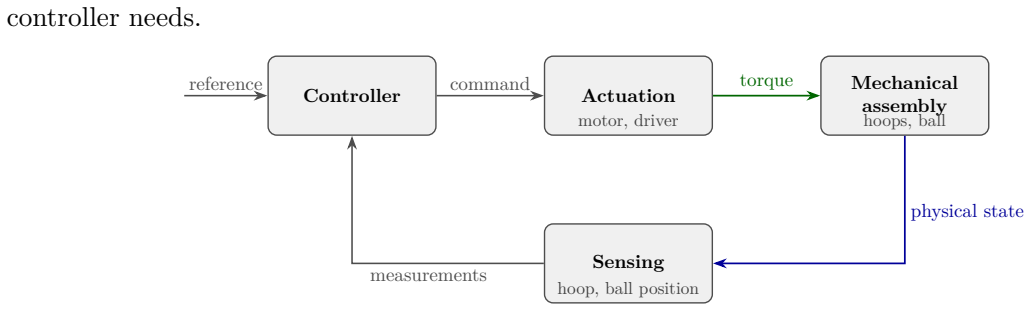
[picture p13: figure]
controller needs.; Controller; Actuation; motor, driver; Mechanical assembly hoops, ball; Sensing; hoop, ball position; reference; command; torque; physical state; measurements

Figure 4.1: Block diagram of the apparatus, showing the four subsystems and the signals exchanged between them.

The loop closes on the ball position, which is the quantity to be controlled and the one that fixes the requirements on everything else. A precision of ∆ψreq = 1◦
is retained as the target, and the resolution of both sensors is derived from it.

The rest of this chapter follows the subsystems in the order in which they constrain one another. The mechanical components come first, since they fix the geometry from which every other requirement is computed. The drive system follows, sized against the most demanding task. The sensors and the embedded computer come last, their requirements being expressed in terms of the geometry and of the dynamics that the previous choices have fixed.

### 4.3 Component Selection

Each component is selected against the requirements stated above, and against the components already retained. For each of them, the constraints are expressed, quantified where it is possible, and confronted with a small number of candidates.

### 4.3.1 Mechanical Components

Ball
Three properties are required of the ball, and candidates are compared in Table 4.1:
- its mass must be uniform, since the model uses the inertia of a homogeneous sphere
- its contact with the track must be dominated by rolling rather than by deformation, since the model carries a viscous coefficient and no viscoelastic term,
- its diameter must be small enough to pass through the opening of the inner hoop.
| Table tennis | Rubber | Chrome steel
Diameter | 40 mm [29] | 25 mm | 25 mm
Mass | 2.7 g [29] | ≈ 11 g | 67 g
Mass distribution | Hollow shell | Uniform | Uniform
Young modulus | Low | 10 MPa to 50 MPa [30] | ≈ 200 GPa

Table 4.1: Comparison of the ball candidates.

The solid chrome steel ball is retained. It is rigid enough for its deformation at the contact to be neglected, its mass is uniformly distributed, and its diameter passes through the opening. The table tennis ball fails on two counts, being a hollow shell whose mass sits near its surface, and being light enough to bounce and to be affected by aerodynamic effects. The rubber ball meets the geometric requirement but not the second one, its rolling behaviour being dominated by viscoelastic losses that no single coefficient describes.

Tracks
Two assumptions of the model bear on the surface the ball rolls on, the no-slip assumption and the planar motion assumption. The first holds only if the contact can supply the force the motion demands, and the second only if the ball is constrained laterally. A bare printed surface answers neither well, which is why dedicated tracks are added to the design.

The friction coefficient needed to sustain rolling follows from the reduced model. It is the ratio between the tangential force demanded by the spin of the ball and the normal force actually available,

µreq(t) = Ft(t)
N(t)

=

2
5mb

Ro

¨θ(t) − Ref fψ¨(t)

mb
g cos ψ(t) + Ref fψ˙(t)
2
. | (4.1)

This ratio varies along a trajectory and grows sharply wherever the normal force becomes small, which is what happens near the top of the hoop. Dry PLA on steel offers µ ≈ 0.52 to 0.67 [31], against µ ≈ 0.6 to 0.86 for rubber on steel [30].

Rubber O-rings of an NBR70 compound are therefore retained as tracks, two per rolling surface. They raise the available friction and hold the ball in a vee that keeps it in the plane of the hoops. Their cord section and their diameters are taken from commercially available standard sizes, so that a damaged ring can be replaced without reprinting anything.

Carrying the ball on two rings rather than on a cylindrical surface has a consequence for the model. The contact occurs at two points instead of one, which displaces the centre of the ball and changes the radius at which it rolls. The correction is derived before any experiment is performed on the plant (see section 5).

Hoops
The hoops fix the geometry of the whole apparatus, and they are dimensioned around the two choices above. They must receive the rings retained as tracks, leave the ball enough room to pass through the opening of the inner hoop, and fit the build volume of the printers available for this work. They must also present a rolling surface whose radius is known accurately, since any error on it propagates into every equation of the model.

Both hoops are printed in PLA by fused deposition modelling, from a parametric model. Printing rather than machining is retained because the geometry is not a simple revolution: the grooves receiving the rings, the opening and the mounting pattern are produced in one operation, and a change of dimension costs a reprint rather than a new fixture. The dimensions of the reference project are taken as a starting point, and adapted to the ball and to the standard ring sizes retained above. The resulting design is shown in Figure 4.2.

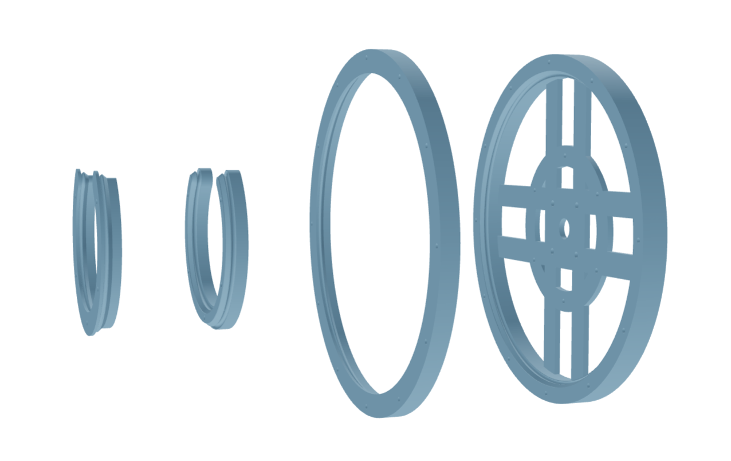
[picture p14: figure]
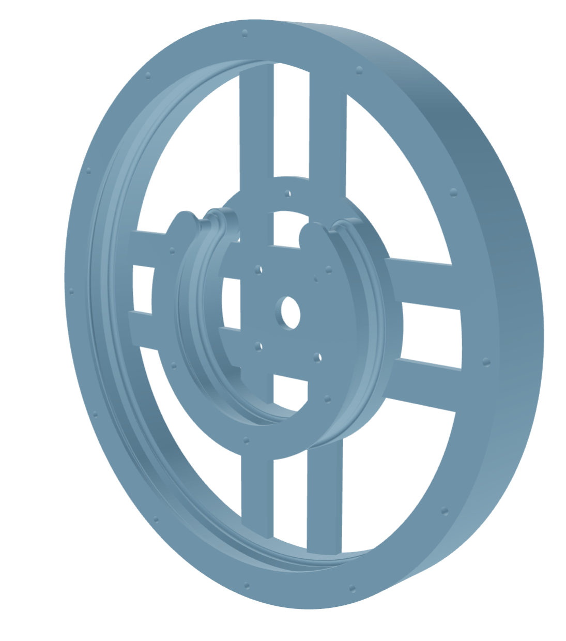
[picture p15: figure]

(a) Assembled view. | (b) Exploded view.

Figure 4.2: CAD model of the two hoops, showing the tracks and the opening of the inner hoop.

### 4.3.2 Drive System

Motor
Two families of actuators are commonly used for this kind of application. Stepper motors offer a simple open-loop control, but their torque drops quickly with increasing speed and they are subject to resonance and to step loss under dynamic loads [32]. Brushless DC motors offer a better power-toweight ratio and a higher efficiency, and produce a continuously variable torque across their operating range when driven in closed loop by Field-Oriented Control, described in Appendix B. The tasks of this work require a smooth torque rather than discrete positioning steps, so a BLDC motor is retained.

The torque the motor must deliver is set by the most demanding task, the looping. To perform it, the gravitational load on the ball must be compensated. The rolling constraint reflects this load onto the hoop. Evaluated at the worst-case ball position, sin ψ = 1, it gives

¨θreq =

5
2

·

g Ref f
Ro (Ro + Rb)

≈ 144 rad s⁻²
, | τreq = Ih
¨θreq ≈ 0.525 N m. | (4.2)

On an actual trajectory, this maximal contribution is reached only for an instant, which makes this estimate an upper bound on the peak torque rather than a value the motor must continuously sustain. The trajectory optimisation (see section 6) returns a maximal peak of 0.473 N m for the same manoeuvre, which confirms that the bound is conservative and that it is the right order of magnitude. Both values rest on the idealised contact geometry. The use of tracks lowers the effective radius and raises the rotational inertia that this contact must accelerate. The corrected geometry is derived once the rings are measured (see section 5): the value moves slightly, but leaves the selection unchanged.

On this basis, the ODrive D5065 270KV motor is retained. Its rated torque of 0.612 N m at 20 A covers the bound comfortably [33], and it is the actuator used in the prototype distributed with the reference project [21]. Its model and characteristics are detailed in Appendix C.

Driver
The driver must implement the Field-Oriented Control algorithm, read the angular position of the rotor, accept commands from the outer controller, and convert them into phase currents. The ODrive S1 is recommended by the manufacturer for the D5065 and implements all of these functions, so its selection is straightforward [34].

The driver also determines whether the input assumed by the model is realisable. The model commands the angular acceleration of the hoops rather than a torque, following the idea that the driver reaches the commanded quantity faster than the mechanical response of the system. This assumption is a property of the velocity loop of the driver, which must be verified rather than assumed. The inner loop is closed internally in the driver, at a rate set by its own tuning. The resulting cascade architecture is the one adopted throughout this work, and the measurement establishing the separation of time scales is reported with the control design (see section 6).

Power supply
The ODrive S1 accepts a DC supply voltage between 12 V and 50.5 V [34]. A 24 V supply is used, comfortably inside that range and below the 32 V rating of the D5065 itself. The phase current required during the most demanding manoeuvre is estimated from the numerical simulation at 14 A to 16 A, so two supplies are connected in parallel, providing up to 20 A combined.

### 4.3.3 Sensors

Two quantities must be measured, the hoop angle θ and the ball angular position ψ. Both sensors are selected against the precision target set earlier, ∆ψreq = 1◦ on the ball position, which is the quantity

the controller acts on and the one from which every other requirement follows.

Hoop angle
The hoop angle is measured by an encoder reading the rotation of the motor shaft, the hoops being rigidly attached to it. The required resolution follows from the target on the ball position. At the contact point, an angular step ∆θ of the hoop produces a linear displacement Ro ∆θ, while the same displacement seen by the ball corresponds to an angular step evaluated at the effective radius of the outer track, Ref f = Ro − Rb. Requiring the contribution of the hoop to match the target gives

∆θreq =

Ref f
Ro

∆ψreq ≈

100
112.5

× 1

- ≈ 0.89◦
. | (4.3)

The AMT102-V encoder, recommended by the manufacturer alongside the motor and driver already retained, provides 2048 pulses per revolution in quadrature, that is 8192 counts per revolution [33]. Its resolution is therefore 360/8192 ≈ 0.044◦
, roughly twenty times finer than required. Such a margin is welcome, because this measurement is also used to estimate the hoop velocity by differentiation, and a coarse resolution would make that estimate noisy.

Ball position
The prototypes reviewed earlier use various sensors for this measurement, from infrared arrays to encoders coupled to the ball itself (see section 2). All of them rely on the ball touching a surface, and therefore report nothing during the free-flight phase. A contactless sensor is the only option compatible with the four tasks, and a Raspberry Pi Camera Module V2 is therefore retained.

This choice has a consequence on the rest of the design: acquiring and processing an image is far more expensive, in memory and in computation, than reading an encoder. This can introduce latency into the control loop, and the image can only be treated by a computer powerful enough to handle image processing. The latency is an important measure of the assembled prototype (see section 5).

The vision pipeline detects the ball by colour segmentation and runs entirely on the embedded computer. It is adapted from the code distributed with the reference project rather than derived from scratch [21], and rewritten for the current versions of the libraries it depends on. Each frame is cropped, converted to a colour space robust to lighting variations, and thresholded to isolate the pixels corresponding to the ball. The centre of the resulting mask gives the position of the ball in pixels, and its offset from the optical centre gives its coordinates (u, v) in the pixels plane, which can then be translated into metric values (u[m]
, v[m]

) and converted into the angle ψ by the relation ψ = atan2(v[m]
, u[m]

). The complete procedure is reported in appendix (see Appendix D).

Two properties of this measurement matter for the design. If the optical axis of the camera remains perpendicular to the hoop plane and passes through the rotation axis, the measurement is independent of the focal length and the working distance. Its precision depends on the number of pixels occupied by the ball in the image, and therefore on the distance at which the camera is placed. Both conditions are enforced during the assembly.

### 4.3.4 Embedded Computer

The last component is the computer. At every control step, it must acquire a frame and extract the ball position from it, read the hoop angle, estimate the two velocities needed by the controller, evaluate the control law, and transmit the resulting command to the driver. All of this must fit within one control period, which is the quantity to be fixed first.

The period is set by the dynamics the loop must follow: the motion of the ball. Linearising the rolling dynamics around the stable equilibrium leads to the natural frequency of the ball oscillating in the hoop. The inner hoop (Reff = 32 mm) being smaller, its natural frequency is higher, and is the most restricting one for the design choices:

f0 =

1
2π

s
g

Ref f

≈ 2.8 Hz, | (4.4)

with the idealised geometry retained so far. Adapting it to the exact geometry with tracks does not change the frequency too much.

A common rule places the sampling frequency between ten and twenty times the dominant dynamics [35], leading to 28 Hz to 56 Hz. A control frequency of 50 Hz is adopted in this work, as in the reference project [2], leaving 20 ms for the whole chain.

The most restricting requirement on the computer itself is linked with the vision pipeline, once again. It needs several hundred megabytes of working memory and must be compatible with libraries such as OpenCV. A Raspberry Pi 3B+ is therefore retained, with its 1 GB of memory. It runs Python natively, and supports the camera through a dedicated interface [36]. Whether the different operations actually fit within the 20 ms budget depends on the resolution and on the implementation. It is measured on the assembled prototype (see section 5).

### 4.4 Assembly

Selecting the components fixes the apparatus on paper, but building it raises a separate question, since several of the assumptions the model rests on are not properties of the components themselves, but of the way they are assembled. The planar motion assumption, in particular, depends on a well-chosen ball and a well-printed hoop but, more importantly, can only hold if the rotating assembly turns about a fixed axis. The assembly is therefore a crucial step in protecting the model.

### 4.4.1 Mechanical Assembly

Both hoops are produced by fused deposition modelling in PLA. Each is printed in two halves, split by a horizontal plane passing between the two grooves of a track. Printing a downward-facing groove would require support material inside the rolling surface itself, and would leave a surface finish incompatible with the rolling assumption. The halves are assembled with M3 screws.

The ball is carried by two O-rings per track, axially separated by 14.7 mm. Three pairs are fitted in total, one for the outer hoop and two for the inner one, one on each of its faces. Since the inner hoop is an open profile of 270°, its rings cannot be fitted whole. They are cut and joined with cyanoacrylate, the junction being placed on a portion of low curvature so that the weakened section carries as little stress as possible.

The hoops are not mounted directly on the motor shaft. A printed adapter is used instead, consisting of a collar engaging the front shaft and a flange bolted to the M3 pattern already carried by the hoops, clamped by an M3 screw threaded into a brass insert.

The prototype is built on an aluminium plate carrying an M6 hole grid of 25 mm pitch. The stator is clamped by a printed support bolted to that grid through L-shaped brackets, setting the rotation axis at 133.5 mm above the plate. The encoder is mounted on the rear shaft, the motor being a double-shaft machine, so that the measurement is taken on the same rigid body as the hoops. Every element of this chain bears on the planar motion assumption, since a hoop mounted eccentrically, a collar loose on the shaft or a support that flexes under the reaction torque all produce an out-of-plane component that the model does not carry. The three printed supports are shown in Figure 4.3.

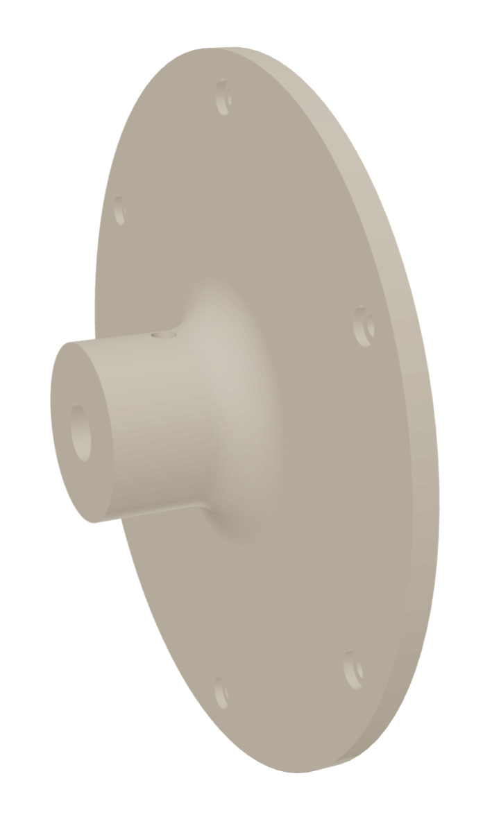
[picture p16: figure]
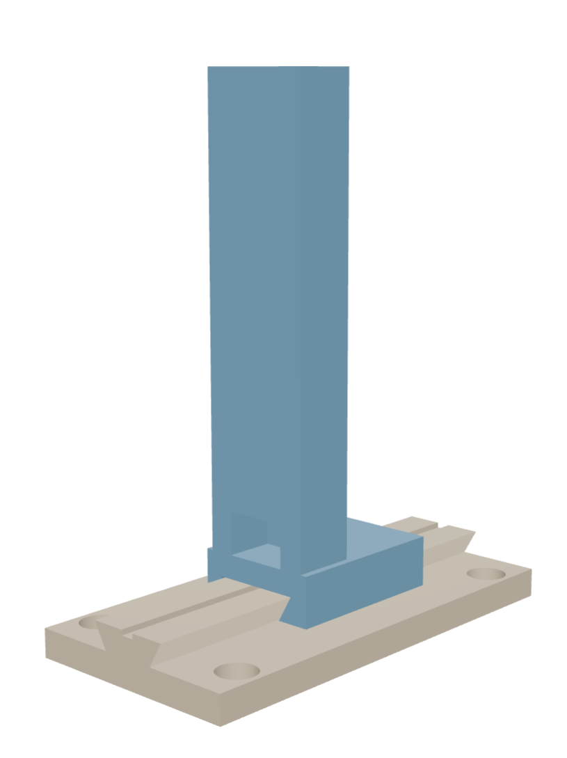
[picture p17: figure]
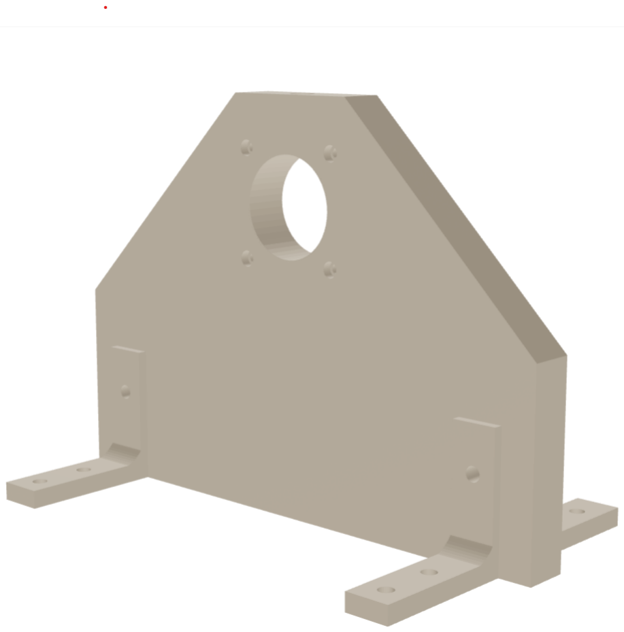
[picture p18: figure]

(a) Shaft adapter. | (b) Motor support. | (c) Camera support and rail.

Figure 4.3: Printed parts holding the apparatus.

### 4.4.2 Camera Support

The measurement of ψ is independent of the focal length, but only if the optical axis is perpendicular to the hoop plane and passes through the rotation axis, as established when the sensor was selected. The support enforces both conditions by construction. Every degree of freedom left to it is a potential source of misalignment, so all are removed except the working distance dcam, which sets the fraction of the image the apparatus occupies and therefore the number of pixels available to locate the ball. The optical axis is fixed at the height of the rotation axis, and the support slides on a rail bolted to the grid through a 60° dovetail. The travel of that rail follows from the field of view of the sensor.

The vertical field of view is the more restrictive, at 48.8°, and an object of diameter D fills a fraction κ of the image at the distance

dcam =

D
2 κ tan(FOVv/2). | (4.5)

With an outer diameter of 237 mm, full coverage requires 261 mm. This extreme is not desirable, leaving no margin around the hoop which makes the rim difficult to detect during the sensor commissioning. The rail provides 77 mm of travel, corresponding to dcam ∈ [266, 344] mm, which spans the useful range of coverage.

### 4.4.3 Electrical Assembly

The electrical assembly connects three chains, the actuation chain comprising the motor, the driver and the encoder, the vision chain comprising the camera and the computer, and the supplies feeding each of them. The architecture is shown in Figure 4.4.

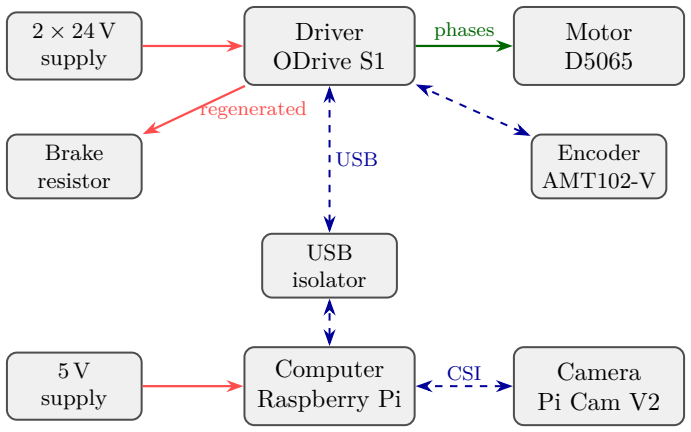
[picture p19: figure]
2 × 24 V supply; 5 V supply; Driver ODrive S1; Motor D5065; Encoder AMT102-V; Brake resistor; Computer Raspberry Pi; Camera Pi Cam V2; USB isolator; phases; regenerated; CSI; USB

Power | Actuation | Signals

Figure 4.4: Electrical architecture of the prototype.

Three connections require care:
- The driver receives a brake resistor of 2 W and 50W, which is not optional here: whenever the hoop decelerates, the motor regenerates energy onto the DC bus, and without a path to dissipate it the bus voltage rises until an over-voltage fault trips the driver [34]. Reversing torques occur during every task of this work, so the condition arises regularly rather than exceptionally.
- The encoder cable is supplied for an earlier ODrive board, so its pinout is adapted manually against the datasheet of the S1 [34].
- The computer communicates with the driver over USB, and the documentation states that USB and the DC input cannot be used simultaneously without an isolator, the two supplies otherwise sharing a ground path through the link [34]. An isolator is therefore fitted.

## 5 Parameter Identification

The previous chapter describes how the apparatus is built. Using it requires one more step: the model is written in terms of physical parameters that the design alone does not supply. Some of them are known by construction, such as the radii of the hoops or the inertia of the ball, but others depend on the specific components and assembly tolerances, and must be measured. They include friction coefficients and the inertia of the rotating assembly.

The identification is made in a fixed order, each step depending on the results of the previous one. The effective geometry is derived first, now that the tracks are chosen. The sensors are then commissioned, since nothing can be identified before the instruments themselves are trusted. Experiments follow, identifying the inertia and friction of the rotating assembly (E1) and the rolling friction of the ball (E2), and a last one validates the complete model (E3).

### 5.1 Effective Contact Geometry

The model treats the ball as rolling on a cylindrical surface at a single contact point, at a distance Ref f = Ro − Rb from the axis, with rolling radius Rb. Neither holds exactly for the assembled prototype: the ball is carried by two O-rings per track, axially separated by h, and therefore touches the track at two points placed symmetrically about its mid-plane.

Rb

(a) Ideal point contact model.

rroll

Rb
∆ | α

h

2 rc

(b) Two-rails contact of the prototype.

Figure 5.1: Contact geometry of the idealised model and of the real prototype.

With Rg the O-ring centreline radius and rc the O-ring cord radius,

∆ = q
(Rb + rc)
2 − (h/2)², | Ref f = Rg − σ∆, | (5.1)

with σ carrying the curvature of the surface, and giving Ref f = 91.6, 67.4 and 32.6 mm for the outer, inner outside and inner inside tracks respectively. The rolling radius, that is the perpendicular distance from a contact point to the spin axis of the ball, follows from the axial offset a = Rb (h/2)/(Rb + rc) of the contact points,

rroll =

q
R²
b − a

2 = Rb

∆ Rb + rc | = 10.64 mm < Rb, | (5.2)

corresponding to a contact half-angle α = arcsin(a/Rb) = 31.7

| ◦ .

The idealised model is recovered when h → 0, since rroll → Rb. Physically, the two contact points define a rolling axis corresponding to a chord of the ball rather than a diameter, so the ball must spin faster than the ideal model predicts to travel the same distance. Its effective rotational inertia is therefore larger, by a factor
k = 1 +

2
5

Rb

rroll

2
| = 1.552, | (5.3)

against 1 + 2/5 = 1.4 for the ideal case. All values are modified accordingly and used in every experiment in control design task (see section 6).
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

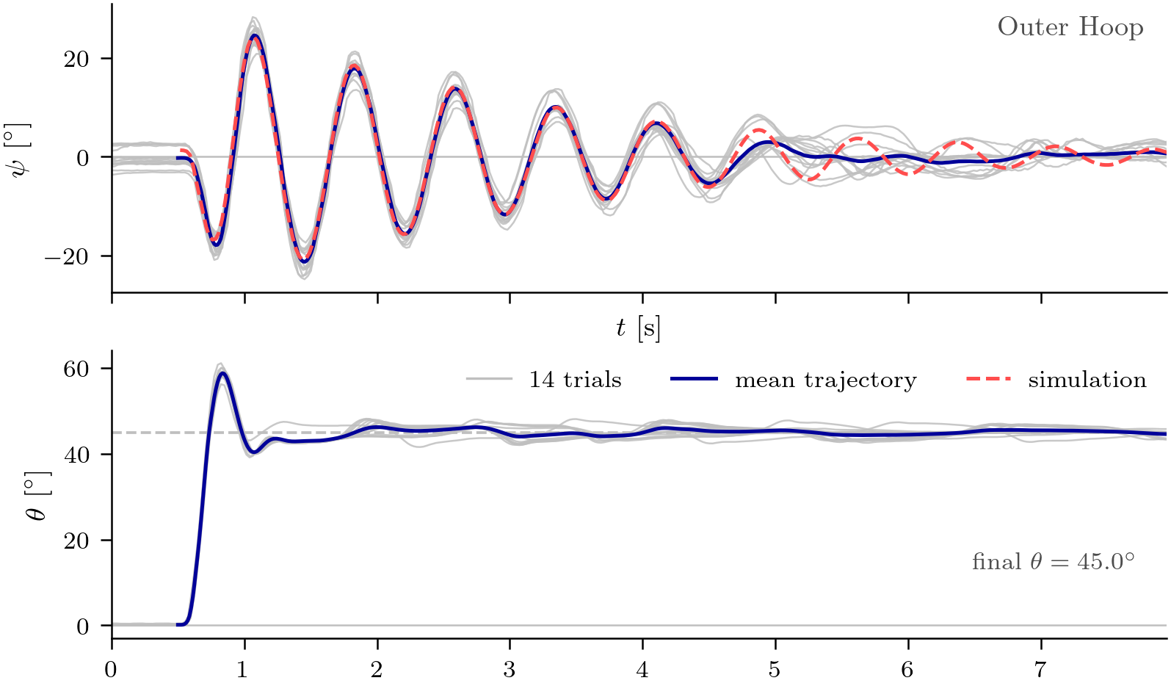
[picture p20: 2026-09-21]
analysis/figures/rapport/E3/theta_psi_outer.png

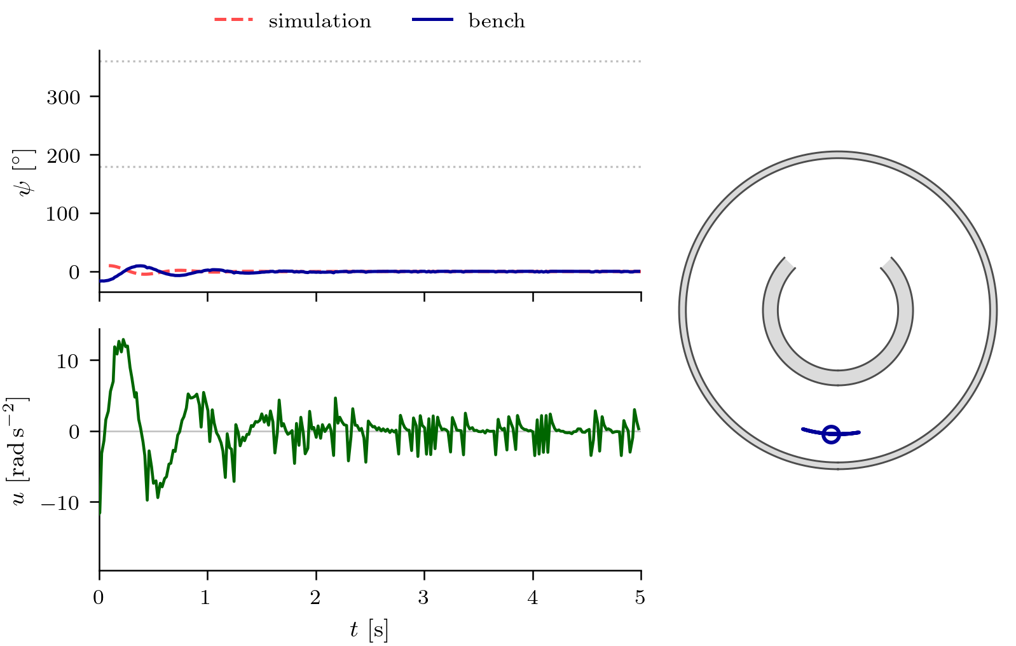
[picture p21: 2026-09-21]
analysis/figures/rapport/T1/T1_outer_10deg.png

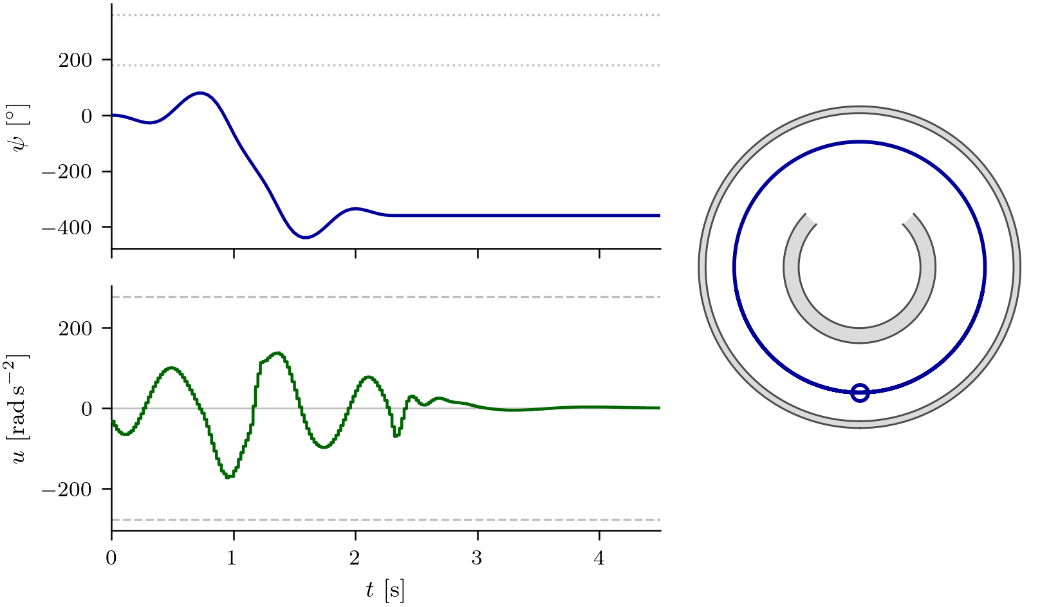
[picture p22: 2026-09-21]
analysis/figures/rapport/T3/trajectory_generation.png

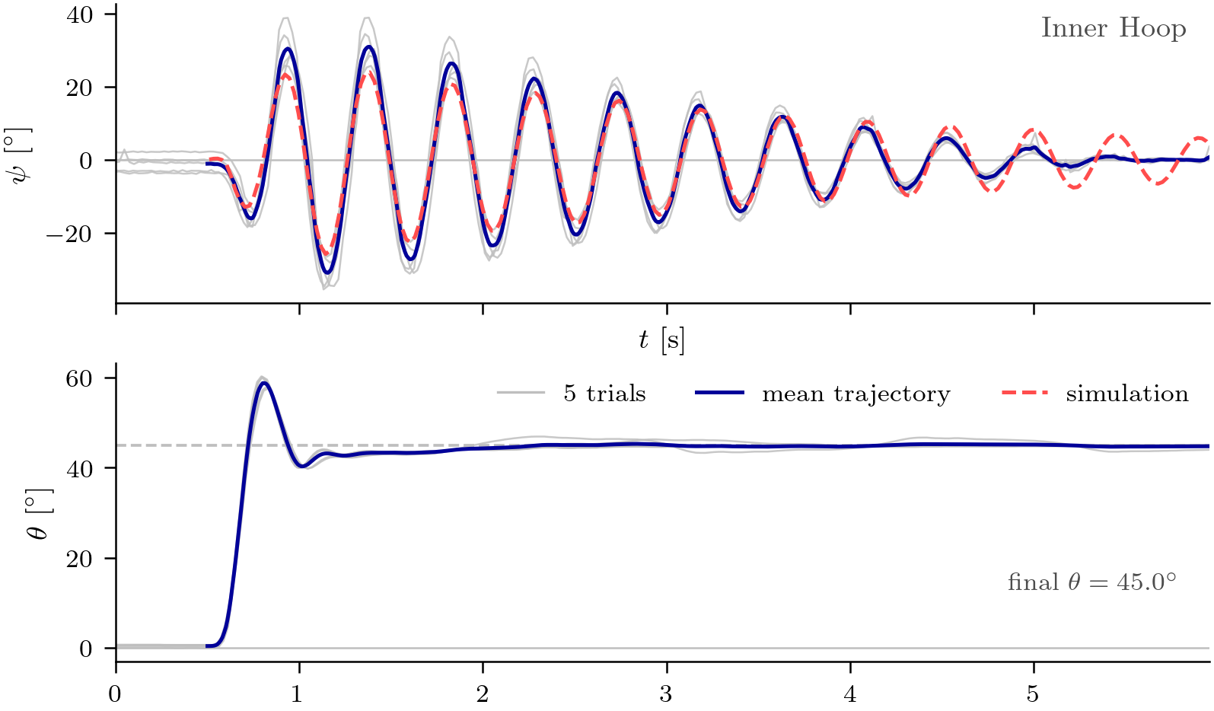
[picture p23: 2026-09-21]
analysis/figures/rapport/E3/theta_psi_inner.png

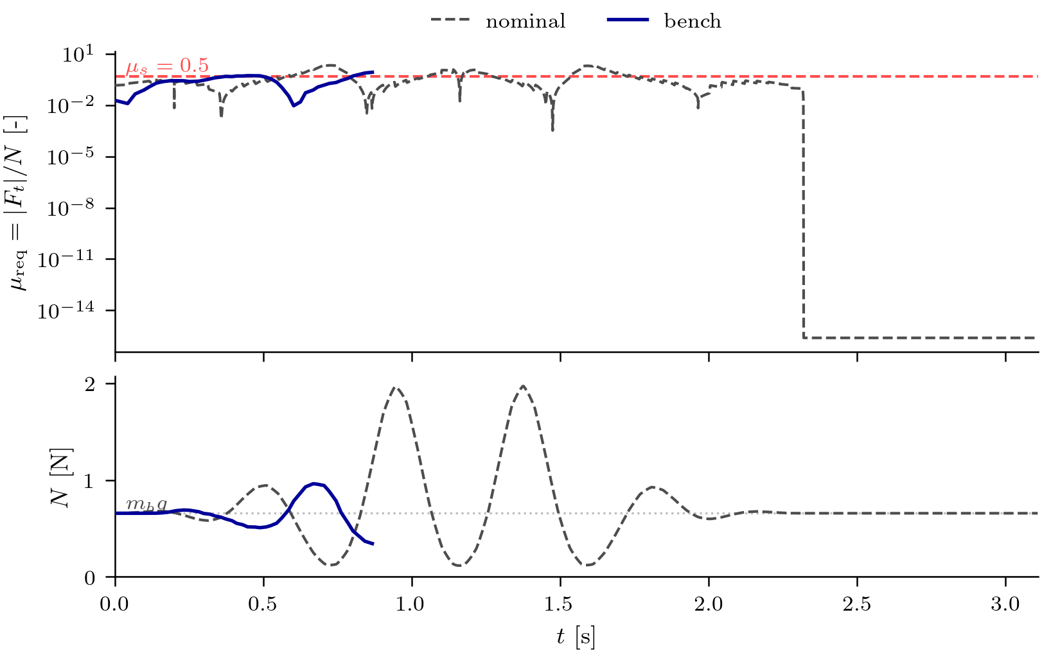
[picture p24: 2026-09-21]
analysis/figures/rapport/T3/trial_183303_adherence.png

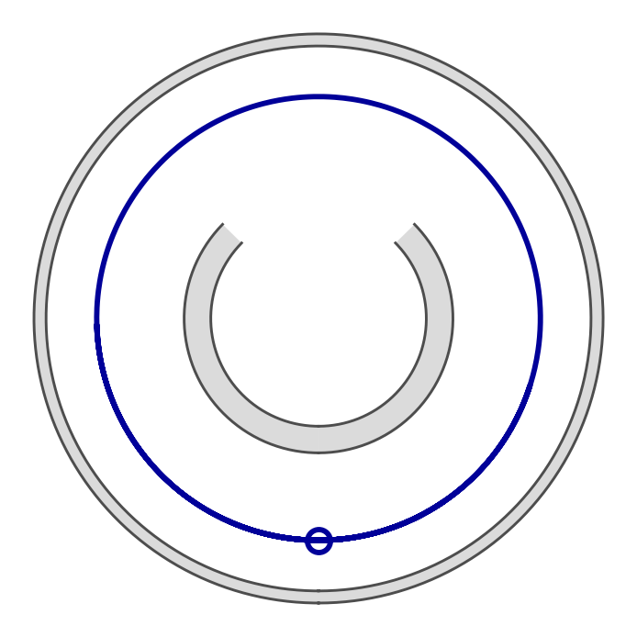
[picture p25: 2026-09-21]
analysis/figures/rapport/T3/path_closed_loop.png

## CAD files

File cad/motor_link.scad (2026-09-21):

// Link between the motor shaft and the hoops.
include <bench.scad>

final_link();

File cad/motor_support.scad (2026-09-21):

// Motor support with its floor brackets.
include <bench.scad>

motor_support_with_fixations();

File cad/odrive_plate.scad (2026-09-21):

// ============================================================================
//  PLAQUE ODrive S1 — version simple
// ============================================================================
//  Une plaque, taille du driver + marge pour 4 trous M6 (fixation plaque alu).
//  Sur la plaque : 4 petits trous pour visser le driver directement.
//
//  Cotes des trous M3 confirmées sur le modèle Onshape officiel ODrive S1
//  (mesure directe, voir commentaire dans la section "Trous M3" ci-dessous).
// ============================================================================

/* ---- Paramètres ---- */

// Empreinte PCB [mm] — source: page produit ODrive S1 (51x64mm)
pcb_L = 64.0;
pcb_W = 51.0;

// Marge ajoutée autour du PCB pour loger les trous M6 (calculée plus bas
// à partir de l'espacement M6 souhaité, ne pas éditer directement)

// Épaisseur de la plaque
thick = 4.0;

// --- Trous M6 vers la plaque aluminium ---
// La grille de la plaque alu a un pas de 25mm en X et en Y (indépendamment).
// Pour tomber pile sur des trous existants quelle que soit la position de
// la plaque sur la grille, l'espacement centre-à-centre des 4 trous M6 doit
// être un multiple de 25mm SUR CHAQUE AXE (X et Y peuvent avoir des
// multiples différents, la grille n'a pas besoin d'être carrée).
m6_hole_d    = 6.5;
m6_spacing_x = 75.0;   // 3 x 25mm
m6_spacing_y = 50.0;   // 2 x 25mm
m6_edge_clear = 8.0;   // marge mini entre trou M6 et bord de plaque [mm]

// --- Trous M3 de fixation du driver (sur le PCB) ---
// Cotes mesurées sur le modèle Onshape officiel (outil Measure) : pattern rectangulaire 60.0mm (X) x 44.0mm (Y), centré sur l'empreinte 64x51mm
// -> inset 2.0mm (X) / 3.5mm (Y) depuis chaque bord. Diamètre mesuré: 3.4mm.
pcb_hole_d = 3.4;   // jeu M3, mesuré (Diameter: 3.400mm sur Onshape)
pcb_holes = [
    [2.0,        3.5],          // coin 1
    [pcb_L-2.0,  3.5],          // coin 2
    [2.0,        pcb_W-3.5],    // coin 3
    [pcb_L-2.0,  pcb_W-3.5],    // coin 4
];

/* ---- Géométrie ---- */

// La plaque doit contenir le pattern M6 (spacing + marge de chaque côté)
// ET le PCB (avec un minimum de marge autour) — on prend le plus grand des deux.
plate_L = max(m6_spacing_x + 2*m6_edge_clear, pcb_L + 10);
plate_W = max(m6_spacing_y + 2*m6_edge_clear, pcb_W + 10);

// PCB centré dans la plaque
off_x = (plate_L - pcb_L) / 2;
off_y = (plate_W - pcb_W) / 2;

// Trous M6 centrés dans la plaque, espacés de m6_spacing_x/y
m6_center_x = plate_L / 2;
m6_center_y = plate_W / 2;

module plate() {
    union() {
        difference() {
            cube([plate_L, plate_W, thick]);

            // Trous M6, espacés de m6_spacing_x (X) et m6_spacing_y (Y), centrés
            m6_positions = [
                [m6_center_x - m6_spacing_x/2,  m6_center_y - m6_spacing_y/2],
                [m6_center_x + m6_spacing_x/2,  m6_center_y - m6_spacing_y/2],
                [m6_center_x - m6_spacing_x/2,  m6_center_y + m6_spacing_y/2],
                [m6_center_x + m6_spacing_x/2,  m6_center_y + m6_spacing_y/2],
            ];
            for (p = m6_positions)
                translate([p[0], p[1], -1])
                    cylinder(d = m6_hole_d, h = thick + 2, $fn = 32);
            }
        // Trous M3 (positions du PCB, décalées de l'offset)
        translate([0, 0 , thick])
        for (h = pcb_holes)
            translate([off_x + h[0], off_y + h[1], -1])
                union() {
                    difference() {
                        union() {
                        cylinder(d = pcb_hole_d, h = thick+2, $fn = 32);
                         translate([0, 0, thick+pcb_hole_d/2]) sphere(d=pcb_hole_d+0.5, $fn=50);
                        }
                        translate([-pcb_hole_d/2-2, -pcb_hole_d/8,0])
                        cube([pcb_hole_d+4, pcb_hole_d/4, thick+8]);
                    }
                   
                }
            
    }
}

plate();

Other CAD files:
cad/assembly.scad
cad/bench.scad
cad/camera_carriage.scad
cad/camera_clearance_test.scad
cad/camera_mount.scad
cad/camera_rail.scad
cad/inner_hoop_down.scad
cad/inner_hoop_up.scad
cad/outer_hoop_down.scad
cad/outer_hoop_up.scad

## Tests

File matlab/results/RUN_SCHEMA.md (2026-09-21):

# The `run` struct schema

Single source of truth for the field names and units of the `run` struct produced
by `build_run.m`, persisted by `save_run.m`/`load_run.m`, and consumed by every
`plot_*` function in `results/visualization/`. `run_scenario.m` builds one for
every scenario, open-loop or closed-loop (docs/MODEL.md sec. 9); an open-loop
scenario's `run` has `ref_psi_rad`/`ref_psi_dot_rad_s`/`error_rad` all-NaN
(there is no reference to track) and `u_rad_s2` all-zero (no controller).
`run_scenario.m` also adds fields beyond this schema for some scenario kinds
(`eig_cl`, `solver_info`, `mode_sequence_check`) — see docs/MODEL.md sec. 9.7,
the source of truth for those rather than a duplicate list here. `source`,
`calibration`, and `ode_segments` (below) are the simulation-vs-hardware
fields — see docs/MODEL.md sec. 10 and docs/VALIDATION.md for how they're
used, not just what they are.

Unit suffix convention: `_Nm` (N·m), `_rad_s2` (rad/s²), `_rad_s` (rad/s), `_rad`
(rad), `_s` (s). A field with no suffix is unitless or not a physical quantity
(strings, structs, timestamps).

## Fields

| Field | Type | Units | Description |
|---|---|---|---|
| `name` | char | — | Scenario name (used for filenames and plot titles) |
| `source` | char | — | `'simulation'` (set by `build_run.m`) or `'experiment'` (set by `import_experiment.m`); every consumer that treats the two differently switches on this field, never on which function produced the struct |
| `t_s` | `N×1 double` | s | Time vector. `t_s(1) = 0` is defined by an explicit event (docs/MODEL.md sec. 10.3) — never by eye |
| `ode_segments` | cell array of ODE solution structs | — | **Simulation only.** One continuous solution struct per `scenario`-run mode interval (same segmentation as `sol.mode_intervals`, dynamics/ball_hoop_ode.m), each usable directly with `deval`. This is what lets `compare_runs.m` resample the simulation onto the experiment's time grid without ever calling `interp1` on discrete samples (docs/MODEL.md sec. 10.4) |
| `calibration` | struct | — | **Experiment only.** Everything needed to map raw sensor output to the state vector — see docs/MODEL.md sec. 10.2 for the field list |
| `x` | `N×6 double` | mixed | State trajectory, one row per `t_s(i)`. Columns match the notation contract's state vector exactly — see table below |
| `tau_Nm` | `N×1 double` | N·m | Applied motor torque, already saturated to `±cfg.tau_max` (the only saturation point is `motor_inner_loop.m`) |
| `u_rad_s2` | `N×1 double` | rad/s² | Controller acceleration setpoint (`u = theta_ddot_ref`) at each `t_s(i)`, before the `u -> tau` conversion |
| `ref_psi_rad` | `N×1 double` | rad | Reference `psi_ref(t)` evaluated along `t_s` |
| `ref_psi_dot_rad_s` | `N×1 double` | rad/s | Reference `psi_dot_ref(t)` evaluated along `t_s` |
| `error_rad` | `N×1 double` | rad | Tracking error, `ref_psi_rad - x(:,5)` |
| `z_ctrl` | `N×n_ctrl double` | mixed | Controller internal state trajectory (e.g. the PID integral term); meaning depends on `ctrl_type` |
| `scenario` | struct | — | Full scenario struct as defined in `scenarios/**/*.m` (docs/MODEL.md sec. 9), kept for reproducibility |
| `params` | struct | — | Physical parameters used for the run (see `ball_hoop_params.m`), kept for reproducibility |
| `cfg` | struct | — | Numerical settings used for the run (see `sim_config.m`), kept for reproducibility |
| `timestamp` | `datetime` | — | Creation time, used to build the `save_run.m` filename |

### `x` columns (notation contract, `ball_hoop_params.m`/dynamics files)

| Column | Symbol | Units | Description |
|---|---|---|---|
| 1 | `r` | m | Ball-centre radial distance from the hoop axis |
| 2 | `r_dot` | m/s | Radial velocity |
| 3 | `theta` | rad | Hoop (motor) angle |
| 4 | `theta_dot` | rad/s | Hoop angular velocity |
| 5 | `psi` | rad | Ball angular position, inertial frame, from the downward vertical |
| 6 | `psi_dot` | rad/s | Ball angular velocity |

## Producers / consumers that must obey this schema

- `results/visualization/build_run.m` — the only place a `run` struct is assembled.
- `results/io/save_run.m` / `results/io/load_run.m` — persist/restore it unchanged.
- `results/visualization/plot_closed_loop_results.m` — reads `t_s`, `x`, `tau_Nm`,
  `ref_psi_rad`, `error_rad`, `cfg.tau_max`, `name`.
- `results/visualization/plot_runs.m` — reads the same fields across multiple
  saved runs for comparison plots.
- `results/visualization/plot_run.m` — the single entry point (Phase 2 target
  item 6); dispatches to the lower-level `plot_*` helpers in
  `results/visualization/plots/`, unpacking `run` into the raw arrays those
  helpers already expect.

## History

Renamed from an earlier, undocumented schema (`t`, `X`, `tau`, `ref_psi`,
`ref_psi_dot`, `error`, `Z_ctrl`) that had no unit suffixes and was never written
down in one place — every consumer had to infer the field meanings from
`build_run.m`'s source. `u_rad_s2` is new: the controller's acceleration setpoint
was computed at every step but never logged, only the post-conversion torque was.

`source`, `ode_segments`, and `calibration` (Phase 6) exist so a simulation run
and an experiment run are the *same struct* — the explicit design goal being
that no plotting or metric function ever needs an "experiment version." See
docs/MODEL.md sec. 10.

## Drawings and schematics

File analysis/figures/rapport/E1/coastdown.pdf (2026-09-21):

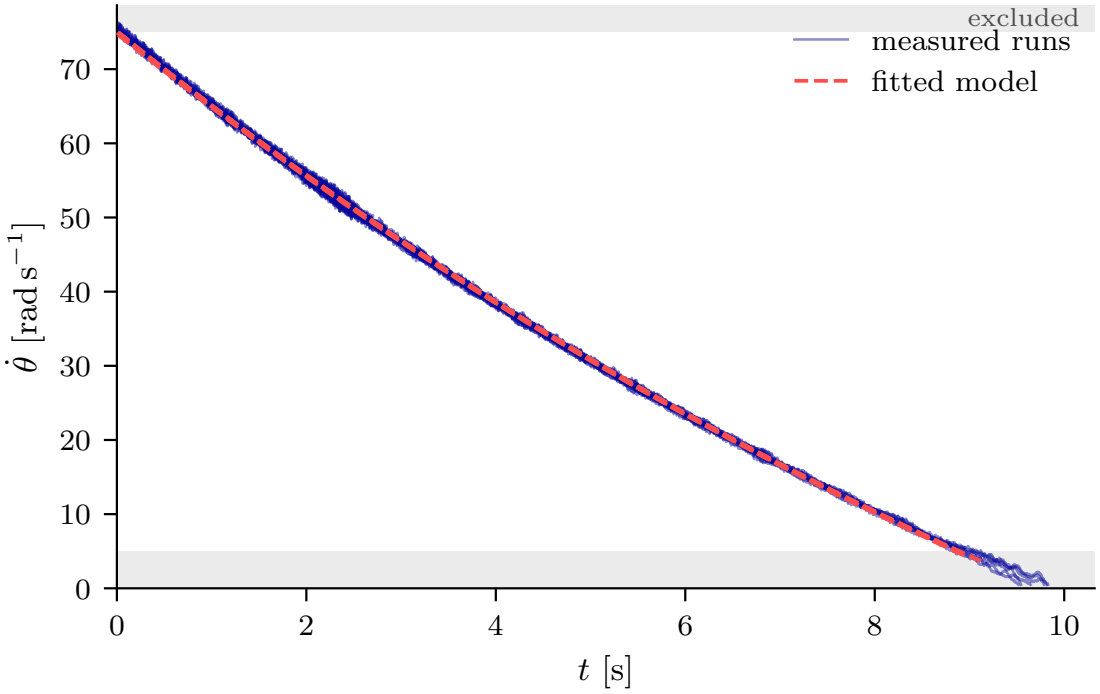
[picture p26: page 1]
θ [rad s−1]; excluded measured runs fitted model

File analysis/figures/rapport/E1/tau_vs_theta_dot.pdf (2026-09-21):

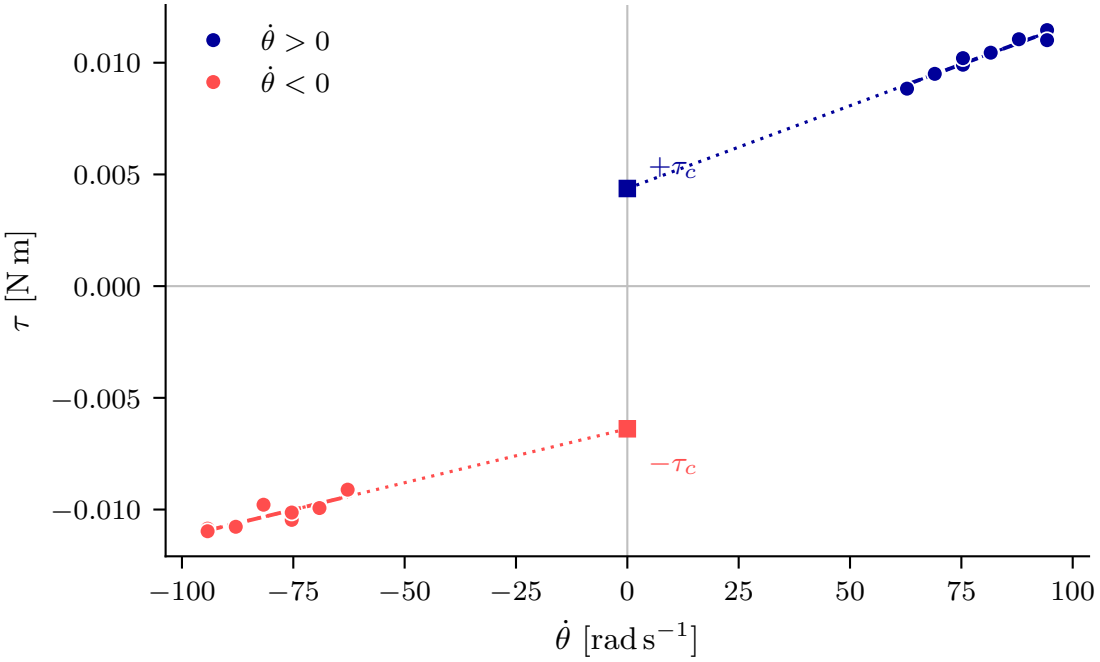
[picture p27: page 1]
˙θ [rad s−1

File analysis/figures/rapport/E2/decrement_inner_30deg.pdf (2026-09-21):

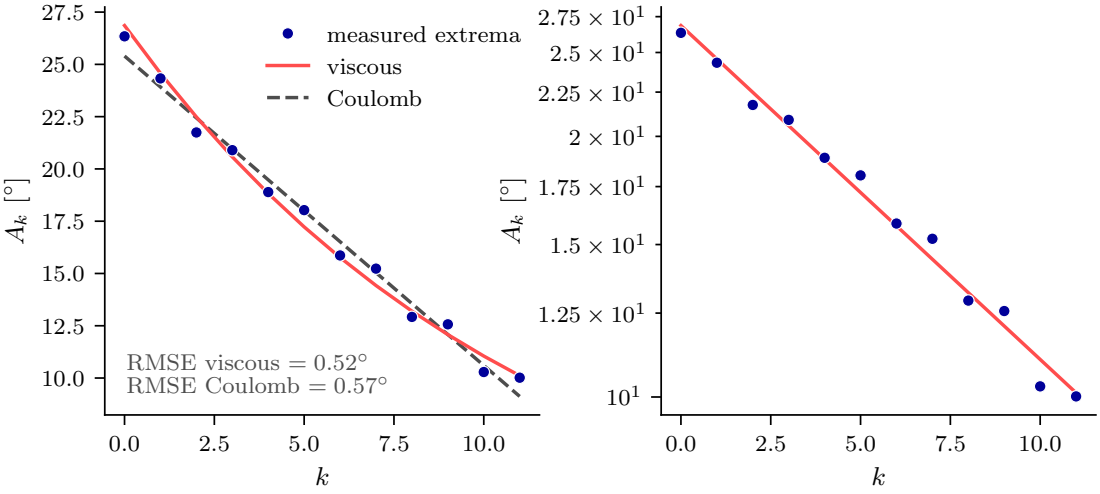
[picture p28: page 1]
RMSE viscous = 0; RMSE Coulomb = 0; measured extrema viscous Coulomb

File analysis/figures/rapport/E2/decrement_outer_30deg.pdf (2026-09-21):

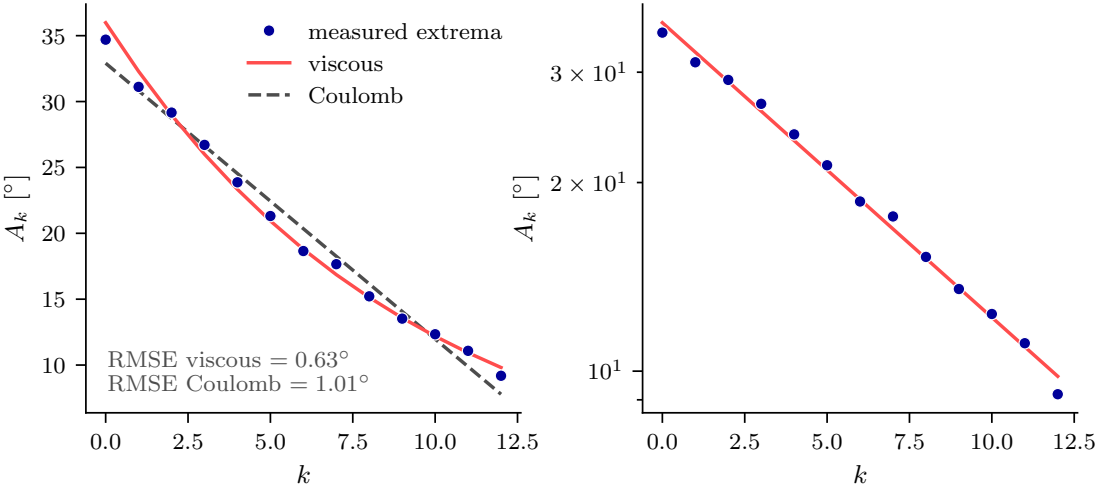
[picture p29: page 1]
RMSE viscous = 0.63◦ RMSE Coulomb = 1.01◦; measured extrema viscous Coulomb

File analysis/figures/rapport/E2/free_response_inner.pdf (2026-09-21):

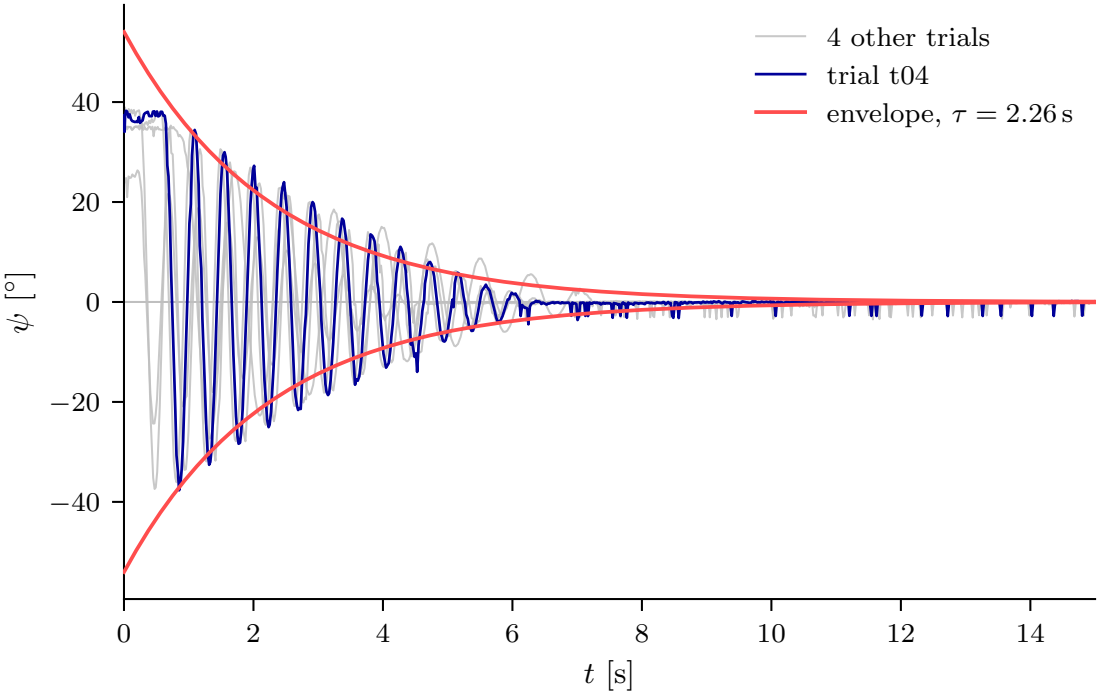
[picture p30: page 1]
4 other trials trial t04 envelope, τ = 2.26 s

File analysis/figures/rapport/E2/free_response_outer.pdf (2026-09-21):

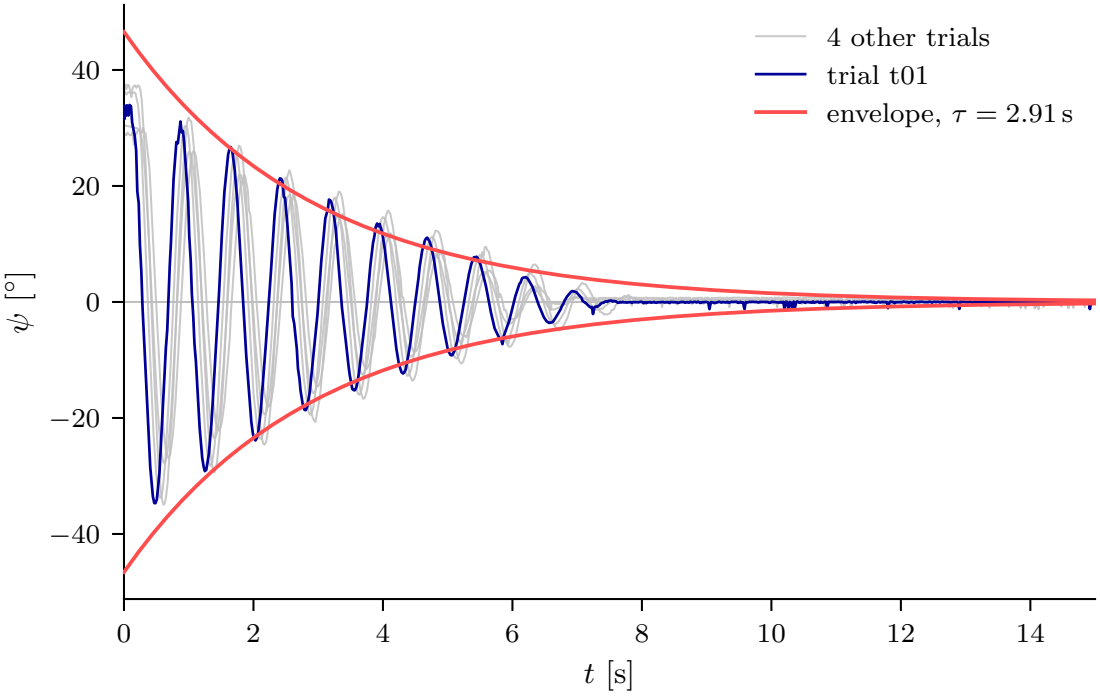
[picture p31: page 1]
4 other trials trial t01 envelope, τ = 2.91 s

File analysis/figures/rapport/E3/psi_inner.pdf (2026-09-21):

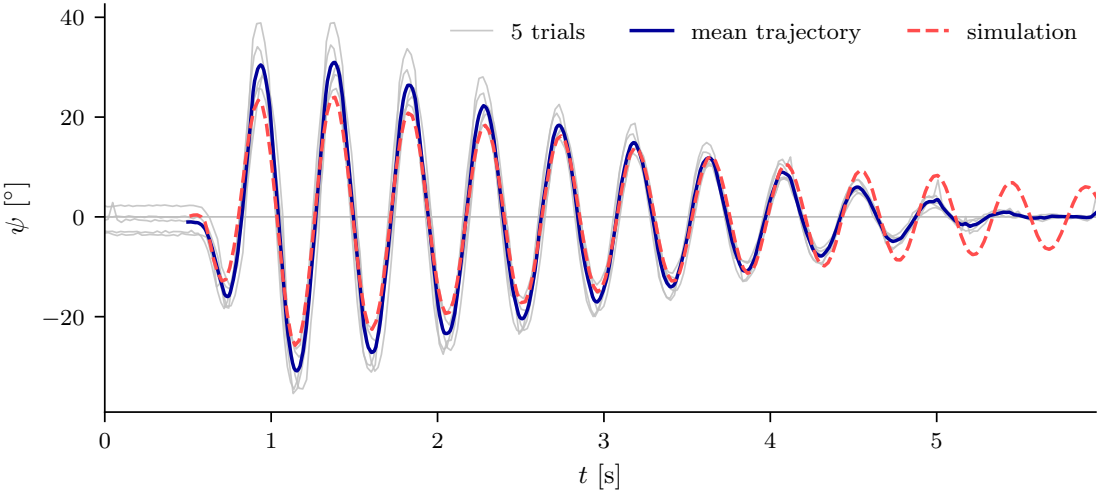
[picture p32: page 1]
5 trials; mean trajectory; simulation

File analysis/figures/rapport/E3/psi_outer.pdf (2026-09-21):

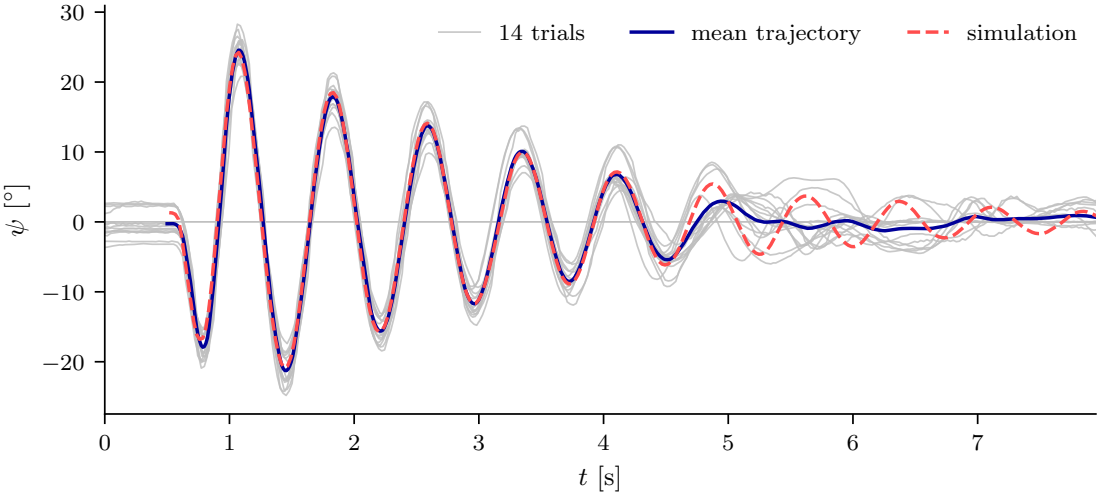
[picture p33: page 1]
14 trials; mean trajectory; simulation

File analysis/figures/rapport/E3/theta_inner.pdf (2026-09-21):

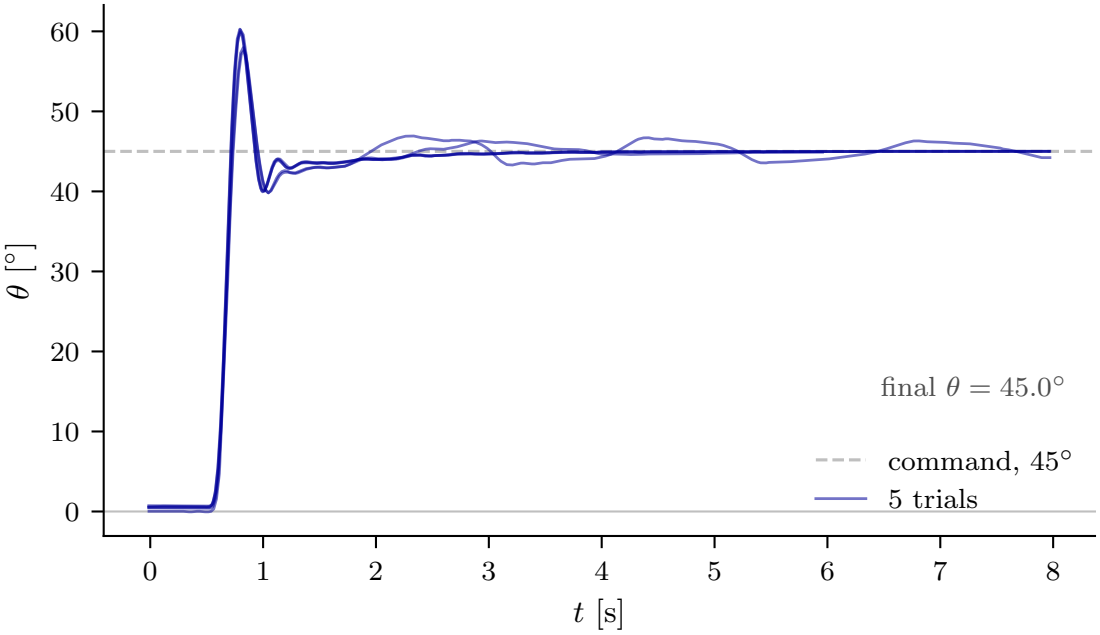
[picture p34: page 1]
final; command, 45; 5 trials

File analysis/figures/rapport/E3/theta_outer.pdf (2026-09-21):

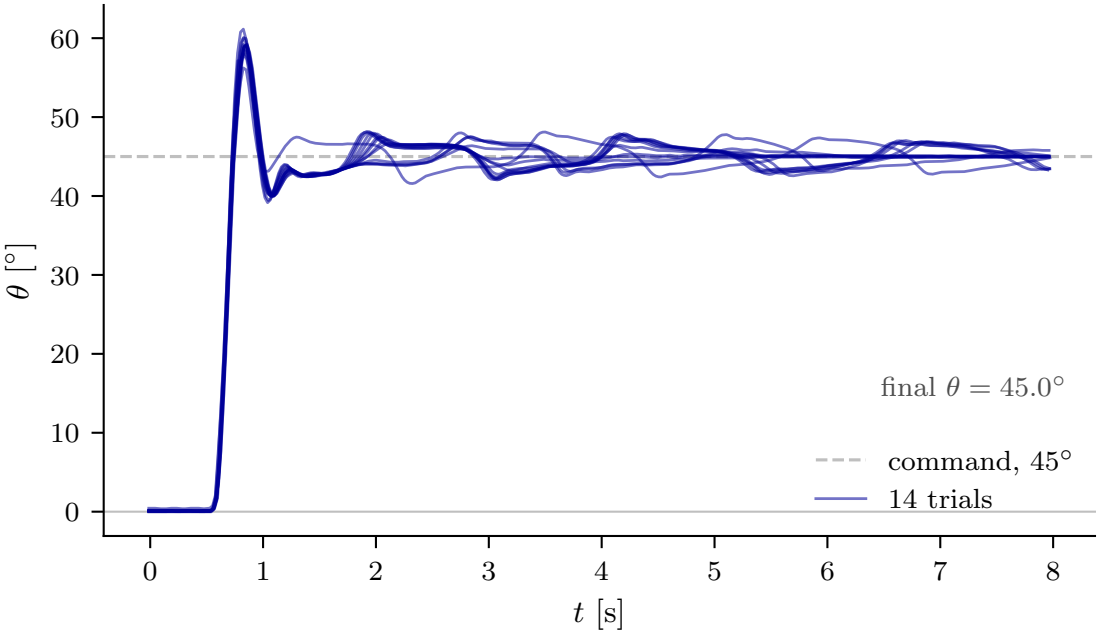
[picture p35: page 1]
final; command, 45; 14 trials

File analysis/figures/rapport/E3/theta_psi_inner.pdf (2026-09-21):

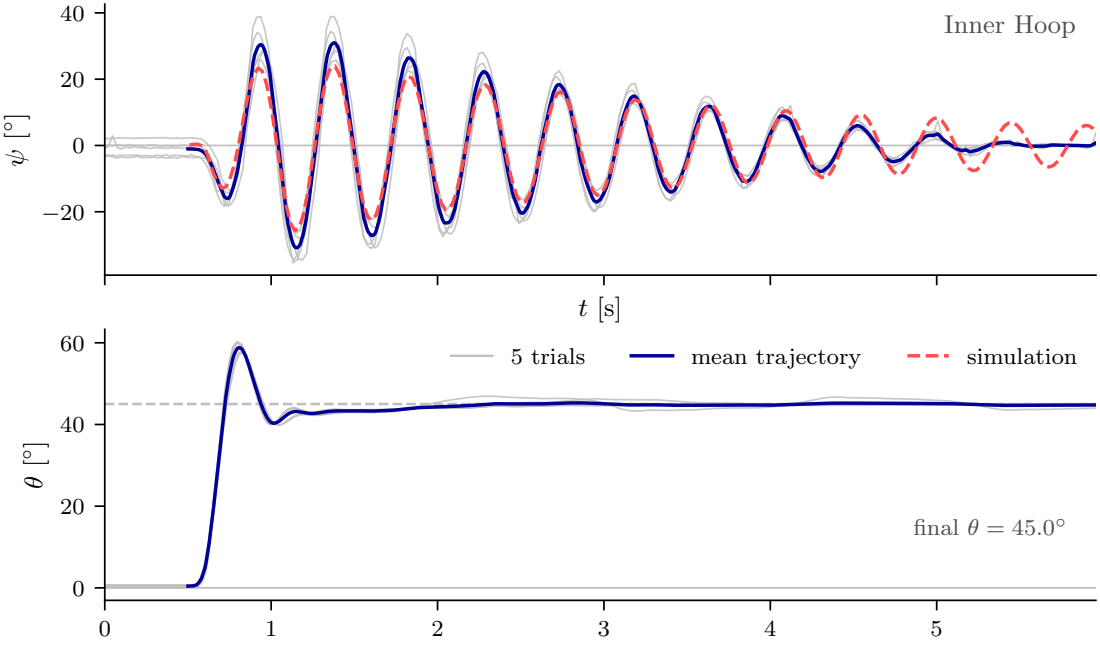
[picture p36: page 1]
Inner Hoop; final θ = 45.0; 5 trials; mean trajectory; simulation

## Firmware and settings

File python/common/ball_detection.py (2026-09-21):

#!/usr/bin/env python3
"""
ball_detection.py -- Portage fidele du detecteur AA4CC + mesure de latence

PIPELINE 
--------------------------------
    1. Combinaison lineaire des canaux -> image scalaire uint8 :
           im = clip(c0*ch0 + c1*ch1 + c2*ch2, 0, 255)
    2. Masque 
    3. Seuillage : cv2.inRange(im, threshold, 255)
    4. Erosion optionnelle (à checker)
    5. cv2.moments -> centroide (m10/m00, m01/m00)
       Validation de l'aire via m00 (sur image binaire 0/255, m00 = aire*255)

processImage(image) : recherche en deux etages
    a. Decimation image[::d, ::d] -> recherche grossiere
       (limites d'aire divisees par d^2)
    b. Fenetre `tracking_window` centree sur le resultat grossier,
       a pleine resolution -> recherche fine
    c. Transformation des coordonnees ROI -> image complete

Usage
-----
    python3 ball_detection.py                      # 200 frames, defauts
    python3 ball_detection.py --n 500 --fps 50
    python3 ball_detection.py --threshold 90 --preview 5
    python3 ball_detection.py --size 480 480 --exposure-us 10000
"""

import argparse
import json
import math
import os
import sys
import time
from datetime import datetime

import numpy as np
import cv2


# =========================================================================== #
#  PARAMETRES DE REFERENCE AA4CC (config.json_sample, detecteur "Red")
# =========================================================================== #

# Coefficients dans l'ordre des canaux du TABLEAU NUMPY, soit (B, G, R)
# avec picamera2/"RGB888". Equivaut a [1, -0.5, -0.5] en RGB chez AA4CC.
DEFAULT_COLOR_COEFS   = (-0.5, -0.5, 1.0)
DEFAULT_THRESHOLD     = 90      # AA4CC "Red"
DEFAULT_DOWNSAMPLE    = 8
DEFAULT_TRACKING_WIN  = 64
DEFAULT_BALL_SIZE     = (0, 150)  # diametre min/max [px] -> aire via pi*(d/2)^2

DEFAULT_RESOLUTION    = (820, 616)
DEFAULT_FPS           = 50
DEFAULT_EXPOSURE_US   = 10000     # 10 ms, valeur AA4CC
DEFAULT_ANALOGUE_GAIN = 12.0


# =========================================================================== #
#  DETECTEUR (portage de detector.ObjectDetector / BallDetector)
# =========================================================================== #

class BallDetectorAA4CC:
    """Portage fidele de detector.BallDetector (AA4CC / raspi-ballpos)."""

    def __init__(self,
                 color_coefs=DEFAULT_COLOR_COEFS,
                 threshold=DEFAULT_THRESHOLD,
                 downsample=DEFAULT_DOWNSAMPLE,
                 tracking_window=DEFAULT_TRACKING_WIN,
                 ball_size=DEFAULT_BALL_SIZE,
                 mask=None,
                 kernel_dwn=None,
                 kernel_roi=None,
                 debug=False):

        self.color_coefs = tuple(float(c) for c in color_coefs)
        self.threshold = int(threshold)
        self.downsample = int(downsample)
        self.tracking_window = int(tracking_window)
        self.debug = bool(debug)

        # BallDetector.__init__ : ball_size (diametres) -> aires,
        # puis ObjectDetector.__init__ multiplie par 255 car, sur une image
        # binaire 0/255, cv2.moments donne m00 = aire_en_pixels * 255.
        if ball_size is not None:
            a_min = (ball_size[0] / 2.0) ** 2 * math.pi
            a_max = (ball_size[1] / 2.0) ** 2 * math.pi
            self.objectlim = (a_min * 255, a_max * 255)
            self.area_px = (a_min, a_max)
        else:
            self.objectlim = None
            self.area_px = None

        self.mask = mask
        self.mask_dwn = (mask[::self.downsample, ::self.downsample]
                         if mask is not None else None)

        self.kernel_dwn = (np.array(kernel_dwn, np.uint8)
                           if kernel_dwn is not None else None)
        self.kernel_roi = (np.array(kernel_roi, np.uint8)
                           if kernel_roi is not None else None)

        self.location = None
        self.images = {}

    @property
    def tracking_window_halfsize(self):
        return self.tracking_window // 2

    # --------------------------------------------------------------- #
    #  findTheObject : coeur de la detection
    # --------------------------------------------------------------- #
    def find_the_object(self, image, object_size_lim=None, mask=None,
                        name=None, kernel=None, store=False):
        """Retourne (cx, cy) en coordonnees LOCALES a `image`, ou None."""

        # Combinaison lineaire des canaux -> image scalaire "de couleur".
        im = np.clip(
            image[:, :, 0] * self.color_coefs[0] +
            image[:, :, 1] * self.color_coefs[1] +
            image[:, :, 2] * self.color_coefs[2],
            0, 255).astype(np.uint8)

        if store:
            self.images[name] = im

        # Masque optionnel. (Source : cv2.bitwise_and(im, self.im, mask=mask)
        # -- `self.im` n'existe pas, bug corrige ici.)
        if mask is not None:
            im = cv2.bitwise_and(im, im, mask=mask)
            if store:
                self.images[name + "_masked"] = im

        # Seuillage
        im_thrs = cv2.inRange(im, self.threshold, 255)

        if kernel is not None:
            im_thrs = cv2.erode(im_thrs, kernel, iterations=1)

        if store:
            self.images[name + "_thrs"] = im_thrs

        M = cv2.moments(im_thrs)
        if M['m00'] > 0 and (object_size_lim is None or
                             object_size_lim[0] < M['m00'] < object_size_lim[1]):
            return M['m10'] / M['m00'], M['m01'] / M['m00']

        if self.debug:
            print("  [debug] aire hors limites (m00={:.0f}, lim={})".format(
                M['m00'], object_size_lim))
        return None

    # --------------------------------------------------------------- #
    #  processImage : recherche en deux etages
    # --------------------------------------------------------------- #
    def process_image(self, image, store=False):
        """Retourne (x, y) en coordonnees de l'image complete, ou None."""
        h, w = image.shape[:2]

        start_y, end_y = 0, h
        start_x, end_x = 0, w

        if store:
            self.images["image"] = image

        # --- Etage grossier : image decimee ---
        if self.downsample > 1:
            image_dwn = image[::self.downsample, ::self.downsample, :]

            if self.objectlim:
                d2 = self.downsample ** 2
                object_lim_dwn = (self.objectlim[0] // d2,
                                  self.objectlim[1] // d2)
            else:
                object_lim_dwn = None

            location_dwn = self.find_the_object(
                image_dwn, object_size_lim=object_lim_dwn,
                mask=self.mask_dwn, name="downsample",
                kernel=self.kernel_dwn, store=store)

            if not location_dwn:
                if self.debug:
                    print("  [debug] objet absent de l'image complete")
                self.location = None
                return None

            center = (int(self.downsample * location_dwn[0]),
                      int(self.downsample * location_dwn[1]))

            halfsize = self.tracking_window_halfsize
            start_y = max(center[1] - halfsize, 0)
            end_y   = min(center[1] + halfsize, h)
            start_x = max(center[0] - halfsize, 0)
            end_x   = min(center[0] + halfsize, w)

            if store:
                self.images["image_dwn"] = image_dwn

        # --- Etage fin : fenetre a pleine resolution ---
        image_roi = image[start_y:end_y, start_x:end_x, :]
        if store:
            self.images["image_roi"] = image_roi

        mask_roi = (self.mask[start_y:end_y, start_x:end_x]
                    if self.mask is not None else None)

        location_in_roi = self.find_the_object(
            image_roi, object_size_lim=self.objectlim, mask=mask_roi,
            name="roi", kernel=self.kernel_roi, store=store)

        if not location_in_roi:
            if self.debug:
                print("  [debug] objet absent de la ROI")
            self.location = None
            return None

        # ROI -> coordonnees image complete
        x = start_x + location_in_roi[0]
        y = start_y + location_in_roi[1]
        self.location = (x, y)
        return self.location


# =========================================================================== #
#  DETECTION AUTOMATIQUE DU HOOP (une seule fois au demarrage)
# =========================================================================== #

def detect_hoop_roi(image, margin=0.05, verbose=True):
    """
    Localise le hoop exterieur et renvoie le rectangle de recadrage.

    Le hoop est fixe dans l'image : cette detection n'est faite qu'une fois,
    au demarrage, et peut donc se permettre d'etre couteuse.
    """
    h_img, w_img = image.shape[:2]
    gray = cv2.cvtColor(image, cv2.COLOR_BGR2GRAY)
    blur = cv2.GaussianBlur(gray, (5, 5), 0)

    circles = cv2.HoughCircles(
        blur, cv2.HOUGH_GRADIENT, dp=1, minDist=h_img // 2,
        param1=80, param2=40,
        minRadius=int(h_img * 0.30), maxRadius=int(h_img * 0.55))

    if circles is not None:
        best = max(circles[0], key=lambda c: c[2])
        cx, cy, r = float(best[0]), float(best[1]), float(best[2])
    else:
        cx, cy, r = w_img / 2.0, h_img / 2.0, h_img * 0.42
        if verbose:
            print("[hoop] Hough n'a rien trouve -> estimation par defaut")

    # --- Raffinement du rayon par scan radial ---
    edges = []
    for i in range(72):
        a = 2 * math.pi * i / 72
        dx, dy = math.cos(a), math.sin(a)
        rs = np.arange(max(0.0, r - 80), r + 80, 0.5)
        xs = (cx + rs * dx).astype(int)
        ys = (cy + rs * dy).astype(int)
        m = (xs >= 0) & (xs < w_img) & (ys >= 0) & (ys < h_img)
        xs, ys, rv = xs[m], ys[m], rs[m]
        if len(xs) < 10:
            continue
        prof = gray[ys, xs].astype(float)
        g = np.abs(np.diff(prof))
        if len(g) == 0:
            continue
        r_edge = rv[int(np.argmax(g))]
        edges.append((cx + r_edge * dx, cy + r_edge * dy, r_edge))

    if len(edges) >= 36:
        e = np.array(edges)
        r = float(np.median(e[:, 2]))
        (cx, cy), _ = cv2.minEnclosingCircle(e[:, :2].astype(np.float32))

    # --- Rectangle de recadrage ---
    half = r * (1.0 + margin)
    x0 = max(int(round(cx - half)), 0)
    y0 = max(int(round(cy - half)), 0)
    x1 = min(int(round(cx + half)), w_img)
    y1 = min(int(round(cy + half)), h_img)

    if verbose:
        lam = 0.237 / (2 * r)
        print("[hoop] centre=({:.0f}, {:.0f})  rayon={:.0f} px  "
              "diametre={:.0f} px".format(cx, cy, r, 2 * r))
        print("[hoop] lambda = {:.3e} m/px | balle 25 mm -> {:.0f} px"
              .format(lam, 0.025 / lam))
        print("[hoop] recadrage : x[{}:{}] y[{}:{}]  ({} x {} px, "
              "marge {:.0f} %)".format(x0, x1, y0, y1,
                                       x1 - x0, y1 - y0, margin * 100))

    return (x0, y0, x1 - x0, y1 - y0)


# =========================================================================== #
#  CAMERA
# =========================================================================== #

def open_camera(size, fps, exposure_us, gain):
    from picamera2 import Picamera2

    picam2 = Picamera2()

    frame_us = int(round(1_000_000 / fps))

    video_config = picam2.create_video_configuration(
        main={
            "size": size,
            "format": "RGB888",
        },
        controls={
            "FrameDurationLimits": (frame_us, frame_us),
            "ExposureTime": int(exposure_us),
            "AnalogueGain": float(gain),
            "AeEnable": False,
            "AwbEnable": False,
            "ColourGains": (1.16, 2.27),
        },
        buffer_count=4,
    )

    picam2.configure(video_config)
    picam2.start()

    print(
        "[cam] {}x{} @ {:.1f} fps | expo {} us | gain {:.1f} | "
        "AWB fixe R={:.2f} B={:.2f}".format(
            size[0], size[1], fps, exposure_us, gain, 1.16, 2.27
        )
    )

    return picam2


# =========================================================================== #
#  BOUCLE PRINCIPALE : acquisition + detection + chronometrage
# =========================================================================== #

def ball_detection(n_frames=200,
                   size=DEFAULT_RESOLUTION,
                   fps=DEFAULT_FPS,
                   exposure_us=DEFAULT_EXPOSURE_US,
                   analogue_gain=DEFAULT_ANALOGUE_GAIN,
                   threshold=DEFAULT_THRESHOLD,
                   color_coefs=DEFAULT_COLOR_COEFS,
                   downsample=DEFAULT_DOWNSAMPLE,
                   tracking_window=DEFAULT_TRACKING_WIN,
                   ball_size=DEFAULT_BALL_SIZE,
                   roi=None,
                   roi_margin=0.05,
                   warmup_frames=10,
                   debug=False,
                   verbose=True):
    """
    Acquiert n_frames, detecte la balle, chronometre chaque etape.
    """
    picam2 = open_camera(size, fps, exposure_us, analogue_gain)

    det = BallDetectorAA4CC(
        color_coefs=color_coefs,
        threshold=threshold,
        downsample=downsample,
        tracking_window=tracking_window,
        ball_size=ball_size,
        debug=debug,
    )

    if verbose:
        print("[det] seuil={} | coefs={} | downsample={} | fenetre={} px"
              .format(threshold, color_coefs, downsample, tracking_window))
        if det.area_px:
            print("[det] aire admise : {:.0f} - {:.0f} px^2"
                  .format(det.area_px[0], det.area_px[1]))

    # Echauffement (frames ignorees)
    for _ in range(warmup_frames):
        picam2.capture_array()

    # --- Recadrage sur le hoop, determine une seule fois ---
    if roi is None:
        roi = detect_hoop_roi(picam2.capture_array(),
                              margin=roi_margin, verbose=verbose)
    rx, ry, rw, rh = roi

    t_acq   = np.empty(n_frames)
    t_det   = np.empty(n_frames)
    t_loop  = np.empty(n_frames)
    t_stamp = np.empty(n_frames)
    U       = np.full(n_frames, np.nan)
    V       = np.full(n_frames, np.nan)
    OK      = np.zeros(n_frames, dtype=bool)

    if verbose:
        print("[run] acquisition de {} frames...".format(n_frames))

    t0 = time.perf_counter()

    for i in range(n_frames):
        ta = time.perf_counter()
        frame = picam2.capture_array()
        tb = time.perf_counter()
      
        loc = det.process_image(frame[ry:ry + rh, rx:rx + rw])
        tc = time.perf_counter()

        t_acq[i]   = (tb - ta) * 1e3
        t_det[i]   = (tc - tb) * 1e3
        t_loop[i]  = (tc - ta) * 1e3
        t_stamp[i] = ta - t0

        if loc is not None:
            # ROI -> coordonnees image complete
            U[i], V[i] = loc[0] + rx, loc[1] + ry
            OK[i] = True

    picam2.stop()
    picam2.close()

    return {
        "t": t_stamp, "u": U, "v": V, "ok": OK,
        "t_acq": t_acq, "t_det": t_det, "t_loop": t_loop,
        "params": {
            "resolution": list(size), "fps": fps,
            "exposure_us": exposure_us, "analogue_gain": analogue_gain,
            "threshold": threshold, "color_coefs": list(color_coefs),
            "downsample": downsample, "tracking_window": tracking_window,
            "ball_size": list(ball_size) if ball_size else None,
            "n_frames": n_frames,
        },
    }


# =========================================================================== #
#  RAPPORT
# =========================================================================== #

def report(res):
    """Affiche le resume des latences et de la detection."""
    t_acq, t_det, t_loop = res["t_acq"], res["t_det"], res["t_loop"]
    ok, t = res["ok"], res["t"]

    def line(label, a):
        print("  {:<22s} {:8.2f} {:8.2f} {:8.2f} {:8.2f} {:8.2f}".format(
            label, a.mean(), np.median(a), a.std(),
            np.percentile(a, 95), a.max()))

    print("\n" + "=" * 72)
    print("  LATENCE")
    print("=" * 72)
    print("  {:<22s} {:>8s} {:>8s} {:>8s} {:>8s} {:>8s}".format(
        "", "Moy", "Med", "Std", "P95", "Max"))
    print("  " + "-" * 68)
    line("Acquisition [ms]", t_acq)
    line("Detection   [ms]", t_det)
    line("Total       [ms]", t_loop)

    # Cadence reellement obtenue, mesuree sur les intervalles entre frames
    dt = np.diff(t) * 1e3
    print("\n  Intervalle entre frames : med {:.2f} ms  p95 {:.2f} ms"
          .format(np.median(dt), np.percentile(dt, 95)))
    print("  Cadence effective       : {:.1f} fps  (p95 : {:.1f} fps)"
          .format(1e3 / np.median(dt), 1e3 / np.percentile(dt, 95)))
    print("  Part acquisition        : {:.0f} % du temps de boucle"
          .format(100 * t_acq.mean() / t_loop.mean()))

    print("\n  Detection : {}/{} ({:.1f} %)".format(
        int(ok.sum()), ok.size, 100.0 * ok.mean()))

    if ok.sum() >= 2:
        u, v = res["u"][ok], res["v"][ok]
        print("  Position u : {:.1f} - {:.1f} px  (etendue {:.0f})".format(
            u.min(), u.max(), u.max() - u.min()))
        print("  Position v : {:.1f} - {:.1f} px  (etendue {:.0f})".format(
            v.min(), v.max(), v.max() - v.min()))
    print()


def save(res, outdir="data/ball_detection"):
    os.makedirs(outdir, exist_ok=True)
    stamp = datetime.now().strftime("%Y%m%d_%H%M%S")
    path = os.path.join(outdir, "balldet_{}.npz".format(stamp))
    np.savez_compressed(
        path,
        t=res["t"], u=res["u"], v=res["v"], ok=res["ok"],
        t_acq=res["t_acq"], t_det=res["t_det"], t_loop=res["t_loop"],
        params=json.dumps(res["params"]),
    )
    print("[out] {}".format(path))
    return path


def preview(n, size, fps, exposure_us, analogue_gain, threshold,
            color_coefs, downsample, tracking_window, ball_size,
            roi=None, roi_margin=0.05,
            outdir="data/ball_detection/preview"):
    """Sauvegarde n frames annotees + les images intermediaires du pipeline."""
    picam2 = open_camera(size, fps, exposure_us, analogue_gain)
    det = BallDetectorAA4CC(color_coefs=color_coefs, threshold=threshold,
                            downsample=downsample,
                            tracking_window=tracking_window,
                            ball_size=ball_size,
                            debug=True)
    os.makedirs(outdir, exist_ok=True)

    for _ in range(10):
        picam2.capture_array()

    if roi is None:
        roi = detect_hoop_roi(picam2.capture_array(), margin=roi_margin)
    rx, ry, rw, rh = roi

    for i in range(n):
        frame = picam2.capture_array()
        crop = frame[ry:ry + rh, rx:rx + rw]
        loc = det.process_image(crop, store=True)

        vis = frame.copy()
        cv2.rectangle(vis, (rx, ry), (rx + rw, ry + rh), (0, 255, 255), 1)
        if loc is not None:
            x, y = int(round(loc[0] + rx)), int(round(loc[1] + ry))
            cv2.drawMarker(vis, (x, y), (0, 255, 0), cv2.MARKER_CROSS, 40, 2)
            cv2.putText(vis, "u={} v={}".format(x, y), (10, 25),
                        cv2.FONT_HERSHEY_SIMPLEX, 0.6, (0, 255, 0), 2)
        else:
            cv2.putText(vis, "NON DETECTEE", (10, 25),
                        cv2.FONT_HERSHEY_SIMPLEX, 0.7, (0, 0, 255), 2)

        cv2.imwrite(os.path.join(outdir, "prev_{:02d}.png".format(i)), vis)
        # Projection couleur SUR LE RECADRAGE : c'est ce que voit le seuil.
        proj = np.clip(
            crop[:, :, 0] * color_coefs[0] + crop[:, :, 1] * color_coefs[1] +
            crop[:, :, 2] * color_coefs[2], 0, 255).astype(np.uint8)
        cv2.imwrite(os.path.join(outdir, "prev_{:02d}_proj.png".format(i)), proj)
        cv2.imwrite(os.path.join(outdir, "prev_{:02d}_thrs.png".format(i)),
                    cv2.inRange(proj, threshold, 255))

        print("  frame {} : proj max={} p99={:.0f} | seuil={}".format(
            i, proj.max(), np.percentile(proj, 99), threshold))
        time.sleep(0)

    picam2.stop()
    picam2.close()
    print("[preview] images dans {}".format(outdir))


# =========================================================================== #
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

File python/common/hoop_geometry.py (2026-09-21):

#!/usr/bin/env python3
"""
hoop_geometry_v3.py -- mesure du centre et du rayon d'orbite de la balle.

POURQUOI CE FICHIER EXISTE
==========================
psi est calcule par control_loop comme

    psi = atan2(u_px - cx, v_px - cy)

ou (cx, cy) = HOOP_CENTRE_PX, une constante figee dans t1_config_v3.py. Tant
que la balle reste au fond (T1/T2), une erreur sur ce centre est absorbee par
l'offset mesure a l'armement : elle est constante et se retranche. Sur un tour
complet elle ne se retranche plus. Un decalage (dx, dy) du centre produit sur
psi une erreur

    dpsi(psi) ~= ( dx cos(psi) - dy sin(psi) ) / R_px

soit une modulation SINUSOIDALE d'amplitude hypot(dx, dy) / R_px, nulle en deux
points seulement et de signe oppose de part et d'autre. Pour 25 px d'ecart sur
une orbite de 208 px cela fait +/- 6.9 deg, et psi_dot en herite d'une
modulation du meme ordre relatif. L'EKF, lui, croit mesurer un angle propre :
aucun reglage de Q ou R ne rattrape un biais qui suit la trajectoire.

Les journaux de la campagne du 11/08 montrent le centre Hough varier de
(385, 275) a (419, 324) d'un essai a l'autre, contre (384.6, 276.6) configure.
Hough n'est donc pas une source de verite exploitable ici : il est refait a
chaque lancement, sur une image, avec un eclairage et une position de camera
qui bougent.

CE QUE FAIT CE SCRIPT
=====================
Il mesure la geometrie UNE FOIS, sur la trajectoire reelle de la balle, et non
sur le cercle apparent du cerceau :

  1. l'operateur fait rouler la balle A LA MAIN, lentement, sur un tour complet
     (plusieurs tours valent mieux) ;
  2. le detecteur journalise le centre de la balle image par image ;
  3. un cercle est ajuste sur le nuage de points au sens des moindres carres
     GEOMETRIQUES (distance orthogonale), ce qui donne d'un seul coup
        - le centre en pixels          -> HOOP_CENTRE_PX
        - le rayon d'ORBITE en pixels  -> HOOP_RADIUS_PX
        - l'echelle lambda             -> R_EFF_M / R_px
        - le residu, donc la confiance qu'on peut leur accorder.

C'est la seule mesure qui repond a la question posee : HOOP_RADIUS_PX doit
decrire le cercle decrit par le CENTRE de la balle, pas le cerceau. Les deux
different du rayon de roulement, et Hough ne mesure ni l'un ni l'autre.

METHODE D'AJUSTEMENT
====================
Deux etapes, la seconde parce que la premiere est biaisee :

  Kasa (algebrique). On resout au sens des moindres carres lineaires
      2 a x_i + 2 b y_i + c = x_i^2 + y_i^2
  d'ou centre (a, b) et R = sqrt(c + a^2 + b^2). Solution exacte et sans
  reglage, mais elle minimise un residu ALGEBRIQUE, pas la distance au cercle :
  l'estimateur est biaise, d'autant plus que l'arc couvert est court
  [Kasa, IEEE Trans. Instrum. Meas. 25(1):8-14, 1976 ; Chernov & Lesort,
   J. Math. Imaging Vis. 23(3):239-252, 2005, sect. 2].

  Gauss-Newton (geometrique). On raffine ensuite en minimisant le vrai cout
      sum_i ( sqrt((x_i-a)^2 + (y_i-b)^2) - R )^2
  dont le jacobien est analytique :
      dr/da = -(x-a)/d,  dr/db = -(y-b)/d,  dr/dR = -1.
  C'est l'estimateur des moindres carres orthogonaux, non biaise a l'ordre
  dominant [Chernov & Lesort, ibid., sect. 3]. Sur un tour complet les deux
  coincident a une fraction de pixel ; l'ecart entre les deux est affiche,
  car un ecart notable signale une couverture angulaire insuffisante.

La couverture angulaire est verifiee explicitement : un cercle ajuste sur un
arc de moins de ~180 deg est mal conditionne, quelle que soit la methode.

SORTIE
======
  - les valeurs a recopier dans la configuration, affichees ;
  - un fichier JSON de calibration, relu par check_geometry() ci-dessous et
    appele par t3_run_v3.py : une configuration qui ne correspond plus a la
    derniere mesure geometrique refuse de partir, au lieu de produire un essai
    ininterpretable.

Usage
-----
    T1_HOOP=outer python3 hoop_geometry_v3.py                 # 30 s
    T1_HOOP=outer python3 hoop_geometry_v3.py --duration 45
    T1_HOOP=inner python3 hoop_geometry_v3.py --exposure 18000

Aucun acces a l'ODrive : le cerceau ne bouge pas, c'est l'operateur qui roule
la balle. Le script est donc sans risque materiel.
"""

import argparse
import json
import math
import os
import time

import numpy as np

from common.ball_detection import (BallDetectorAA4CC, open_camera,
                            DEFAULT_COLOR_COEFS)


CALIB_DIR = os.path.dirname(os.path.abspath(__file__))


def calib_path(hoop):
    return os.path.join(CALIB_DIR, "hoop_geometry_{}.json".format(hoop))


# =========================================================================== #
#  Ajustement de cercle
# =========================================================================== #

def fit_circle_kasa(x, y):
    """Ajustement algebrique. Retourne (cx, cy, R).

    Systeme lineaire  M @ [2a, 2b, c] = x^2 + y^2, resolu par lstsq : pas
    d'inversion explicite, donc robuste a un mauvais conditionnement.
    """
    M = np.column_stack([x, y, np.ones(x.size)])
    rhs = x ** 2 + y ** 2
    sol, *_ = np.linalg.lstsq(M, rhs, rcond=None)
    a, b = 0.5 * sol[0], 0.5 * sol[1]
    R = math.sqrt(max(sol[2] + a ** 2 + b ** 2, 0.0))
    return a, b, R


def fit_circle_geometric(x, y, p0, n_iter=50, tol=1e-9):
    """Moindres carres orthogonaux par Gauss-Newton. Retourne (cx, cy, R).

    Le residu r_i = d_i - R est la distance SIGNEE au cercle. Le jacobien est
    exact ; aucune approximation numerique, aucun pas a regler.
    """
    a, b, R = p0
    for _ in range(n_iter):
        dx, dy = x - a, y - b
        d = np.hypot(dx, dy)
        d = np.where(d < 1e-12, 1e-12, d)
        r = d - R
        J = np.column_stack([-dx / d, -dy / d, -np.ones(d.size)])
        step, *_ = np.linalg.lstsq(J, -r, rcond=None)
        a, b, R = a + step[0], b + step[1], R + step[2]
        if np.max(np.abs(step)) < tol:
            break
    return a, b, R
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
